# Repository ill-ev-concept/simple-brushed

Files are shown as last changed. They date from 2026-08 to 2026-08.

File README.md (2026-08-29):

# Ethan Brushed Simple

This is the simple version of the brushed motor controller for EV3, my current documentation can be found [here](https://docs.google.com/document/d/1gfZzmsv_RstbJ-Lk0RfqkkH_zSeoGgdf7qZ41NG-Wzg/edit?usp=sharing)

Additionally, the code can be found <a href = "https://gitlab.engr.illinois.edu/ev-concept/software2022-23/embedded/brushed-motors/brushed-motor-simple-26-27">here</a>

Currently works on the bench with minor modifications and problems:

 - Footprint for mosfet is reversed, so bodge wire was used to swap trace for gate pin
 - Buck converter possibly having some issues, previously worked in testing, but now doesnt function so it is being bypassed
 - Gate driver IC seems to pull down the STMs PWM signal to 2 volts peak, which is just enough for it to detect, but 3.3v is prefered

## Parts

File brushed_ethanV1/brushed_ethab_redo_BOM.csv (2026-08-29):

Reference | Qty | Value | DNP | Exclude from BOM | Exclude from Board | Footprint | Datasheet |  | ordered? | do I have in bring home box?
C1,C2,C4,C5,C7,C17,C18,C19 | 8 | .1uF |  |  |  | Capacitor_SMD:C_0805_2012Metric_Pad1.18x1.45mm_HandSolder |  |  | y | y but they are 0603
C3,C6 | 2 | 1uF |  |  |  | Capacitor_SMD:C_0805_2012Metric_Pad1.18x1.45mm_HandSolder |  |  | y | y
C8,C9 | 2 | C |  |  |  | Capacitor_THT:CP_Radial_D18.0mm_P7.50mm |  |  | y | y
C10,C11,C12 | 3 | 1.0uF |  |  |  | Capacitor_SMD:C_1206_3216Metric |  |  | y | y
C13 | 1 | 100nF |  |  |  | Capacitor_SMD:C_0603_1608Metric_Pad1.08x0.95mm_HandSolder |  |  | y | y
C14 | 1 | 100nF |  |  |  | Capacitor_SMD:C_0402_1005Metric_Pad0.74x0.62mm_HandSolder |  |  | y | y
C15,C16 | 2 | 10.0uF |  |  |  | Capacitor_SMD:C_1210_3225Metric |  |  | y | y
D1,D2 | 2 | LED |  |  |  | LED_SMD:LED_0805_2012Metric_Pad1.15x1.40mm_HandSolder |  |  | y | y
IC1 | 1 | TC1108-3.3VDBTR |  |  |  | SamacSys_Parts:SOT230P700X180-4N | http://ww1.microchip.com/downloads/en/DeviceDoc/21357C.pdf |  | y | y
J1 | 1 | RJ45 |  |  |  | Connector_RJ:RJ45_Amphenol_54602-x08_Horizontal |  |  | alr have | y
J2 | 1 | Conn_02x05_Odd_Even |  |  |  | Connector_PinSocket_2.54mm:PinSocket_2x05_P2.54mm_Vertical |  |  | alr have | y
J3 | 1 | Conn_01x03 |  |  |  | Connector_PinSocket_2.54mm:PinSocket_1x03_P2.54mm_Vertical |  |  | alr have | y
J4 | 1 | Conn_01x05 | DNP |  | Excluded from board | Connector_PinSocket_2.54mm:PinSocket_1x05_P2.54mm_Vertical
L1 | 1 | 22uH |  |  |  | Inductor_SMD:L_Bourns_SRR1208_12.7x12.7mm |  |  | y | y
M1 | 1 | Motor_DC |  |  | Excluded from board
MP1,MP2,MP3,MP4 | 4 | WP-BUFU |  |  |  | WP-BUFU:WP-BUFU_7461097 |  |  | y | y
Q2 | 1 | NTBLS4D0N15MC |  |  |  | SamacSys_Parts:NTBLS4D0N15MC | https://www.onsemi.com/pub/Collateral/NTBLS4D0N15MC-D.PDF |  | y | y
R1 | 1 | 120 |  |  |  | Resistor_SMD:R_0805_2012Metric_Pad1.20x1.40mm_HandSolder
R3 | 1 | 100k |  |  |  | Resistor_SMD:R_0402_1005Metric_Pad0.72x0.64mm_HandSolder |  |  | y | y
R4 | 1 | 7.15k |  |  |  | Resistor_SMD:R_0603_1608Metric_Pad0.98x0.95mm_HandSolder |  |  | y | y
R9 | 1 | 10 |  |  |  | Resistor_SMD:R_0805_2012Metric_Pad1.20x1.40mm_HandSolder |  | 10ohm | y | y
R10 | 1 | 10k |  |  |  | Resistor_SMD:R_0805_2012Metric_Pad1.20x1.40mm_HandSolder |  |  | y | y
R14,R15 | 2 | 300 |  |  |  | Resistor_SMD:R_0805_2012Metric_Pad1.20x1.40mm_HandSolder |  |  | alr have |  | ig not bringing these home
R16 | 1 | 100k |  |  |  | Resistor_SMD:R_0805_2012Metric_Pad1.20x1.40mm_HandSolder |  |  | y | y
R17 | 1 | 3k |  |  |  | Resistor_SMD:R_0805_2012Metric_Pad1.20x1.40mm_HandSolder |  |  | y | y
TP7 | 1 | TestPoint |  |  |  | TestPoint:TestPoint_Pad_D1.0mm
U1 | 1 | STM32F103C8Tx |  |  |  | Package_QFP:LQFP-48_7x7mm_P0.5mm | https://www.st.com/resource/en/datasheet/stm32f103c8.pdf |  | y | y
U2 | 1 | ISO1050DUB |  |  |  | Package_SO:SOP-8_6.62x9.15mm_P2.54mm | http://www.ti.com/lit/ds/symlink/iso1050.pdf |  | alr have | y
U3 | 1 | LMR51625YDDCR |  |  |  | BrushedDC2:BUCK_LMR51625YDDCR | https://www.ti.com/lit/gpn/lmr51625 |  | y | y
U4 | 1 | DGD0211CWT-7 |  |  |  | gatedriver:TSOT25-TH_DIO | DGD0211CWT-7 |  | y at home
U5 | 1 | STPS30H100DJF-TR |  |  |  | BrushedDC2:MOSFET_100DJF-TR_STM | https://www.st.com/resource/en/datasheet/stps30h100djf.pdf |  | y | y
VR1 | 1 | P120PK-Y25BR10K |  |  |  | SamacSys_Parts:P120PKY25BR10K | https://www.ttelectronics.com/TTElectronics/media/ProductFiles/Datasheet/P120.pdf |  | y | y

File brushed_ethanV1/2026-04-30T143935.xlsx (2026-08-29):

DigiKey - Shopping Cart
Index | Quantity | Part Number | Manufacturer Part Number | Description | Customer Reference | Available | Backorder | Unit Price | Extended Price USD
1 | 50 | 490-3261-1-ND | GRM155R71C104KA88D | CAP CER 0.1UF 16V X7R 0402 |  | 50 | 0 | 0.0156 | 0.78
2 | 25 | 445-4467-1-ND | C3216X7R2A105K160AA | CAP CER 1UF 100V X7R 1206 |  | 25 | 0 | 0.26 | 6.50
3 | 50 | 490-3285-1-ND | GRM188R72A104KA35D | CAP CER 0.1UF 100V X7R 0603 |  | 50 | 0 | 0.0584 | 2.92
4 | 25 | 587-MSASU32MSB5106KPNA01CT-ND | MSASU32MSB5106KPNA01 | CAP CER 10UF 50V X5R 1210 |  | 25 | 0 | 0.335 | 8.38
5 | 10 | 118-SRR1208-220MLCT-ND | SRR1208-220ML | FIXED IND 22UH 3.5A 43 MOHM SMD |  | 10 | 0 | 0.77 | 7.70
6 | 50 | 541-100KLCT-ND | CRCW0402100KFKED | RES 100K OHM 1% 1/16W 0402 |  | 50 | 0 | 0.0192 | 0.96
7 | 10 | 296-LMR51625XDDCRCT-ND | LMR51625XDDCR | SIMPLE SWITCHER SYNCHRONOUS BUCK |  | 10 | 0 | 1.545 | 15.45
8 | 10 | 497-15671-1-ND | STPS30H100DJF-TR | DIODE SCHOTTKY 100V 30A PWRFLAT |  | 10 | 0 | 1.181 | 11.81
9 | 25 | 311-100KCRCT-ND | RC0805FR-07100KL | RES 100K OHM 1% 1/8W 0805 |  | 25 | 0 | 0.0236 | 0.59
10 | 25 | A126368CT-ND | CRG0805F3K0 | RES SMD 3K OHM 1% 1/8W 0805 |  | 25 | 0 | 0.0276 | 0.69
11 | 50 | RMCF0603FT7K15CT-ND | RMCF0603FT7K15 | RES 7.15K OHM 1% 1/10W 0603 |  | 50 | 0 | 0.012 | 0.60
12 | 50 | 399-C0603C104K3RACTUCT-ND | C0603C104K3RACTU | CAP CER 0.1UF 25V X7R 0603 |  | 50 | 0 | 0.0358 | 1.79
13 | 10 | 1276-1066-1-ND | CL21B105KAFNNNE | CAP CER 1UF 25V X7R 0805 |  | 10 | 0 | 0.049 | 0.49
14 | 10 | 565-EKYB101ELL102MM40S-ND | EKYB101ELL102MM40S | CAP ALUM 1000UF 20% 100V RADIAL |  | 10 | 0 | 4.26 | 42.60
15 | 10 | 160-1179-1-ND | LTST-C170GKT | LED GREEN CLEAR SMD |  | 10 | 0 | 0.087 | 0.87
16 | 10 | TC1108-3.3VDBTRCT-ND | TC1108-3.3VDBTR | IC REG LIN 3.3V 300MA SOT-223-3 |  | 10 | 0 | 0.69 | 6.90
17 | 12 | 732-3217-ND | 7461097 | TERM REDCUBE M6 16PIN PCB |  | 12 | 0 | 3.013 | 36.16
18 | 10 | 488-NTBLS4D0N15MCCT-ND | NTBLS4D0N15MC | MOSFET N-CH 150V 19A/187A 8HPSOF |  | 10 | 0 | 5.164 | 51.64
19 | 10 | 541-10.0CCT-ND | CRCW080510R0FKEA | RES SMD 10 OHM 1% 1/4W 0805 |  | 10 | 0 | 0.044 | 0.44
20 | 50 | RMCF0805FT10K0CT-ND | RMCF0805FT10K0 | RES 10K OHM 1% 1/8W 0805 |  | 50 | 0 | 0.0156 | 0.78
21 | 4 | 497-17666-1-ND | STM32F103C8T6TR | IC MCU 32BIT 64KB FLASH 48LQFP |  | 4 | 0 | 6.15 | 24.60
22 | 4 | 987-1710-ND | P120PK-Y25BR10K | POT 10K OHM 1/20W PLASTIC LINEAR |  | 4 | 0 | 1.42 | 5.68

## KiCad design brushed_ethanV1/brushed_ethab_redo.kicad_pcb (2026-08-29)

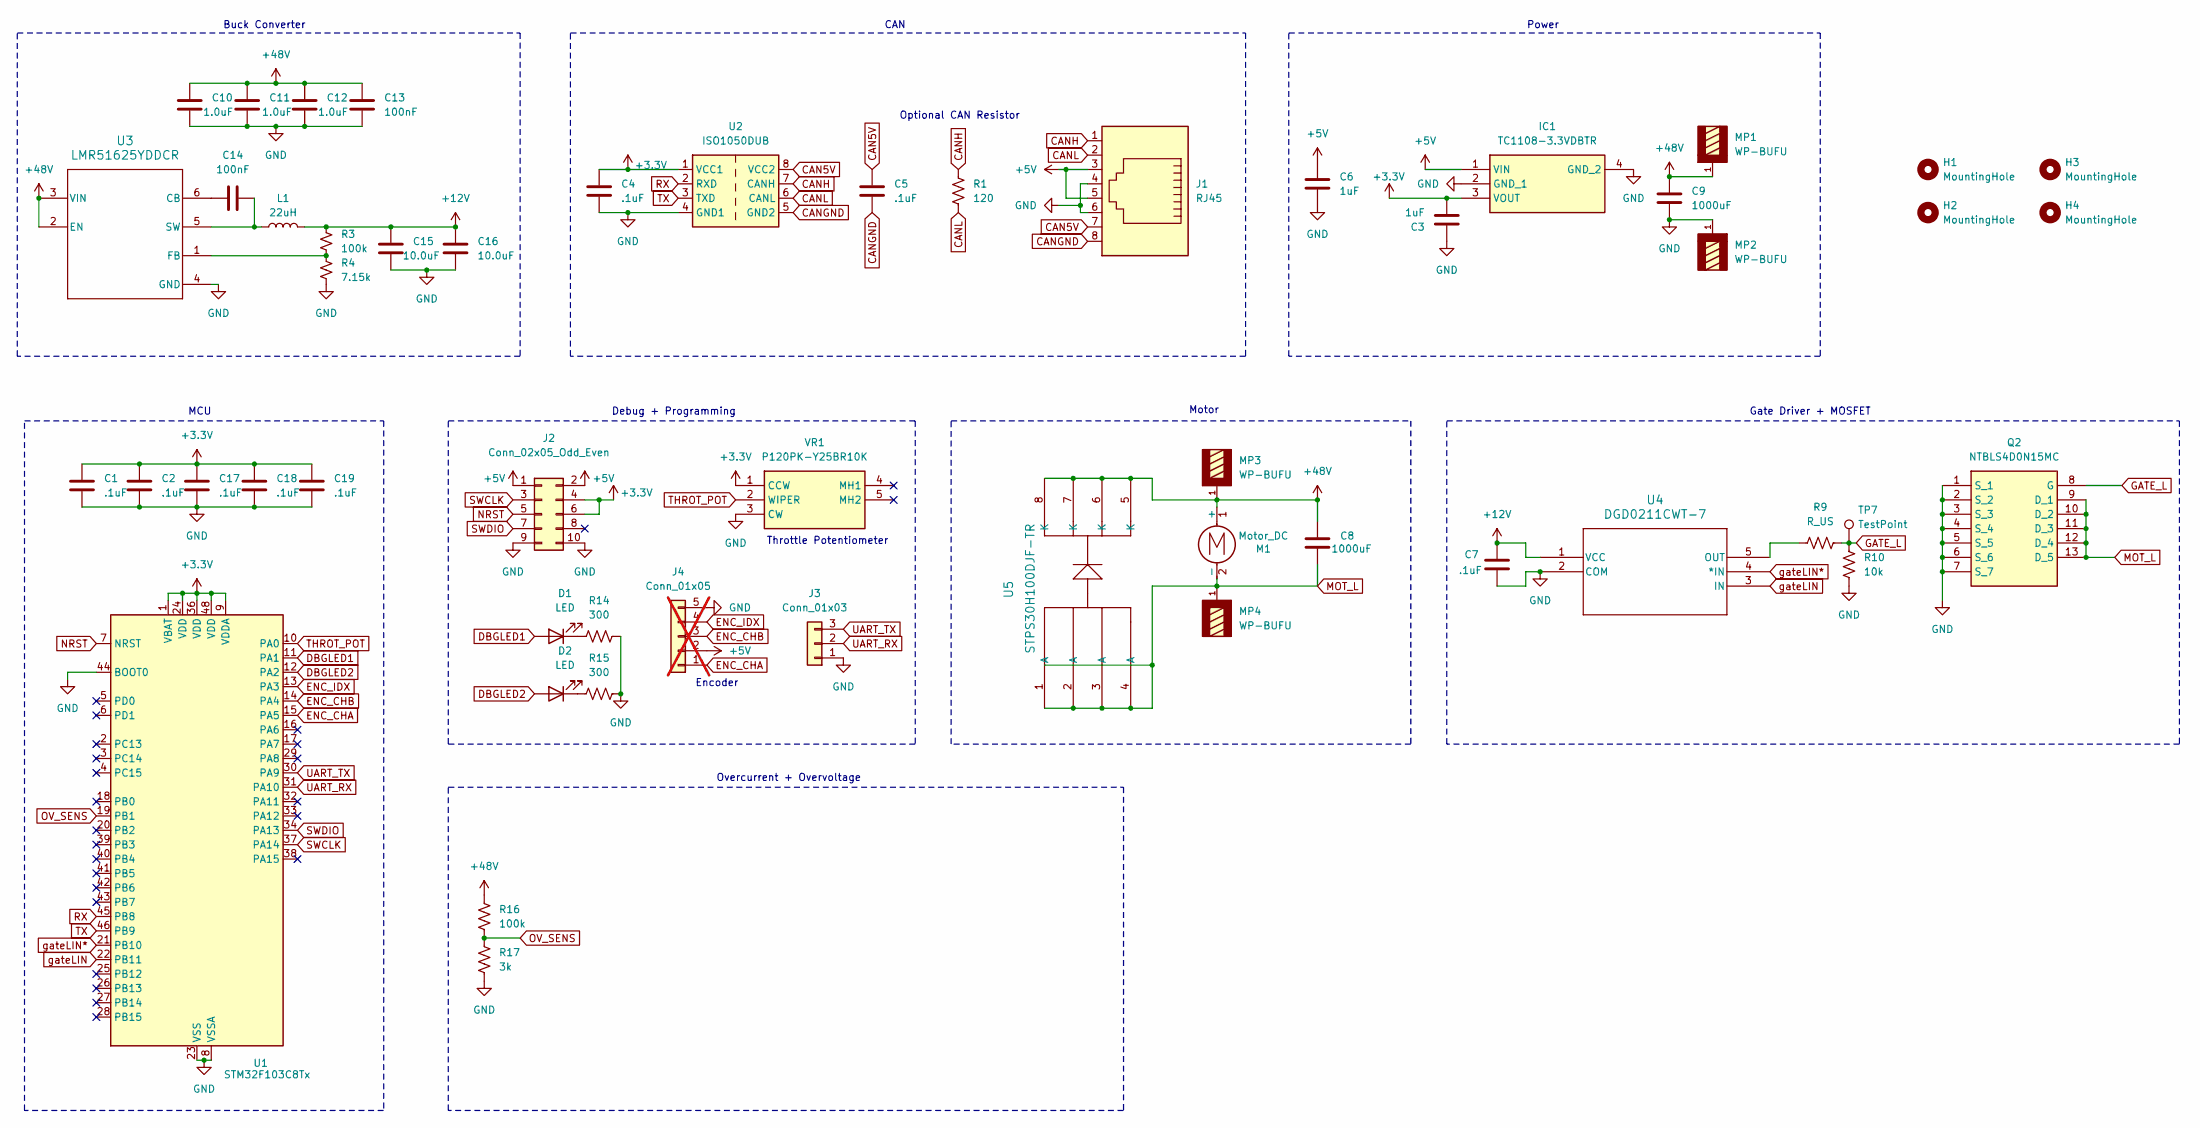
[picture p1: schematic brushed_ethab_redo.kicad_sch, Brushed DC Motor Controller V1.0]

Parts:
C1, C2, C4, C5, C7, C17, C18, C19: .1uF; C_0805_2012Metric_Pad1.18x1.45mm_HandSolder
C3, C6: 1uF; C_0805_2012Metric_Pad1.18x1.45mm_HandSolder
C8, C9: 1000uF; CP_Radial_D18.0mm_P7.50mm
C10, C11, C12: 1.0uF; C_1206_3216Metric
C13: 100nF; C_0603_1608Metric_Pad1.08x0.95mm_HandSolder
C14: 100nF; C_0402_1005Metric_Pad0.74x0.62mm_HandSolder
C15, C16: 10.0uF; C_1210_3225Metric
D1, D2: LED; LED_0805_2012Metric_Pad1.15x1.40mm_HandSolder
H1, H2, H3, H4: MountingHole; MountingHole_4.3mm_M4
IC1: TC1108-3.3VDBTR; SOT230P700X180-4N; Manufacturer_Part_Number TC1108-3.3VDBTR; Mouser Part Number 579-TC1108-3.3VDBTR
J1: RJ45; RJ45_Amphenol_54602-x08_Horizontal
J2: Conn_02x05_Odd_Even; PinSocket_2x05_P2.54mm_Vertical
J3: Conn_01x03; PinSocket_1x03_P2.54mm_Vertical
J4: Conn_01x05; PinSocket_1x05_P2.54mm_Vertical; not fitted
L1: 22uH; L_Bourns_SRR1208_12.7x12.7mm
M1: Motor_DC
MP1, MP2, MP3, MP4: WP-BUFU; WP-BUFU_7461097; DigiKey_Part_Number 732-3217-ND
Q2: NTBLS4D0N15MC; Manufacturer_Part_Number NTBLS4D0N15MC; Mouser Part Number 863-NTBLS4D0N15MC
R1: 120; R_0805_2012Metric_Pad1.20x1.40mm_HandSolder
R3: 100k; R_0402_1005Metric_Pad0.72x0.64mm_HandSolder
R4: 7.15k; R_0603_1608Metric_Pad0.98x0.95mm_HandSolder
R9: R_US; R_0805_2012Metric_Pad1.20x1.40mm_HandSolder
R10: 10k; R_0805_2012Metric_Pad1.20x1.40mm_HandSolder
R14, R15: 300; R_0805_2012Metric_Pad1.20x1.40mm_HandSolder
R16: 100k; R_0805_2012Metric_Pad1.20x1.40mm_HandSolder
R17: 3k; R_0805_2012Metric_Pad1.20x1.40mm_HandSolder
TP7: TestPoint; TestPoint_Pad_D1.0mm
U1: STM32F103C8Tx; LQFP-48_7x7mm_P0.5mm
U2: ISO1050DUB; SOP-8_6.62x9.15mm_P2.54mm
U3: LMR51625YDDCR; BUCK_LMR51625YDDCR
U4: DGD0211CWT-7; TSOT25-TH_DIO
U5: STPS30H100DJF-TR; MOSFET_100DJF-TR_STM
VR1: P120PK-Y25BR10K; P120PKY25BR10K; Manufacturer_Part_Number P120PK-Y25BR10K; Mouser Part Number 858-P120PKY25BR10K

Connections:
+3.3V: C1.1, C2.1, C3.2, C4.1, C17.1, C18.1, C19.1, IC1.3 (VOUT), J2.4, J2.6, U1.1 (VBAT), U1.9 (VDDA), U1.24 (VDD), U1.36 (VDD), U1.48 (VDD), U2.1 (VCC1), VR1.1 (CCW)
+5V: C6.1, IC1.1 (VIN), J1.3, J1.5, J2.1, J2.2, J4.2
+12V: C7.1, C15.1, C16.1, L1.2, R3.1, U4.1 (VCC)
+48V: C8.1, C9.1, C10.1, C11.1, C12.1, C13.1, M1.1 (+), MP1.1, MP1.2, MP1.3, MP1.4, MP1.5, MP1.6, MP1.7, MP1.8, MP1.9, MP1.10, MP1.11, MP1.12, MP1.13, MP1.14, MP1.15, MP1.16, MP3.1, MP3.2, MP3.3, MP3.4, MP3.5, MP3.6, MP3.7, MP3.8, MP3.9, MP3.10, MP3.11, MP3.12, MP3.13, MP3.14, MP3.15, MP3.16, R16.2, U3.2 (EN), U3.3 (VIN), U5.5 (K), U5.6 (K), U5.7 (K), U5.8 (K)
CAN5V: C5.1, J1.7, U2.8 (VCC2)
CANGND: C5.2, J1.8, U2.5 (GND2)
CANH: J1.1, R1.1, U2.7 (CANH)
CANL: J1.2, R1.2, U2.6 (CANL)
DBGLED1: D1.2 (A), U1.11 (PA1)
DBGLED2: D2.2 (A), U1.12 (PA2)
ENC_CHA: J4.1, U1.15 (PA5)
ENC_CHB: J4.3, U1.14 (PA4)
ENC_IDX: J4.4, U1.13 (PA3)
GATE_L: Q2.8 (G), R9.2, R10.2, TP7.1 (1_1)
GND: C1.2, C2.2, C3.1, C4.2, C6.2, C7.2, C9.2, C10.2, C11.2, C12.2, C13.2, C15.2, C16.2, C17.2, C18.2, C19.2, IC1.2 (GND_1), IC1.4 (GND_2), J1.4, J1.6, J2.9, J2.10, J3.1, J4.5, MP2.1, MP2.2, MP2.3, MP2.4, MP2.5, MP2.6, MP2.7, MP2.8, MP2.9, MP2.10, MP2.11, MP2.12, MP2.13, MP2.14, MP2.15, MP2.16, Q2.1 (S_1), Q2.2 (S_2), Q2.3 (S_3), Q2.4 (S_4), Q2.5 (S_5), Q2.6 (S_6), Q2.7 (S_7), R4.2, R10.1, R14.2, R15.2, R17.1, U1.8 (VSSA), U1.23 (VSS), U1.35 (VSS), U1.44 (BOOT0), U1.47 (VSS), U2.4 (GND1), U3.4 (GND), U4.2 (COM), VR1.3 (CW)
MOT_L: C8.2, M1.2 (-), MP4.1, MP4.2, MP4.3, MP4.4, MP4.5, MP4.6, MP4.7, MP4.8, MP4.9, MP4.10, MP4.11, MP4.12, MP4.13, MP4.14, MP4.15, MP4.16, Q2.9 (D_1), Q2.10 (D_2), Q2.11 (D_3), Q2.12 (D_4), Q2.13 (D_5), U5.1 (A), U5.2 (A), U5.3 (A), U5.4 (A)
NRST: J2.5, U1.7 (NRST)
unnamed: D1.1 (K), R14.1
unnamed: D2.1 (K), R15.1
unnamed: C14.1, U3.6 (CB)
unnamed: R3.2, R4.1, U3.1 (FB)
unnamed: C14.2, L1.1, U3.5 (SW)
unnamed: R9.1, U4.5 (OUT)
OV_SENS: R16.1, R17.2, U1.19 (PB1)
RX: U1.45 (PB8), U2.2 (RXD)
SWCLK: J2.3, U1.37 (PA14)
SWDIO: J2.7, U1.34 (PA13)
THROT_POT: U1.10 (PA0), VR1.2 (WIPER)
TX: U1.46 (PB9), U2.3 (TXD)
UART_RX: J3.2, U1.31 (PA10)
UART_TX: J3.3, U1.30 (PA9)
gateLIN: U1.22 (PB11), U4.3 (IN)
gateLIN*: U1.21 (PB10), U4.4 (*IN)

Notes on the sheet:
Buck Converter
Power
Encoder
Optional CAN Resistor
Throttle Potentiometer
Motor
MCU
CAN
Gate Driver + MOSFET
Overcurrent + Overvoltage
Debug + Programming

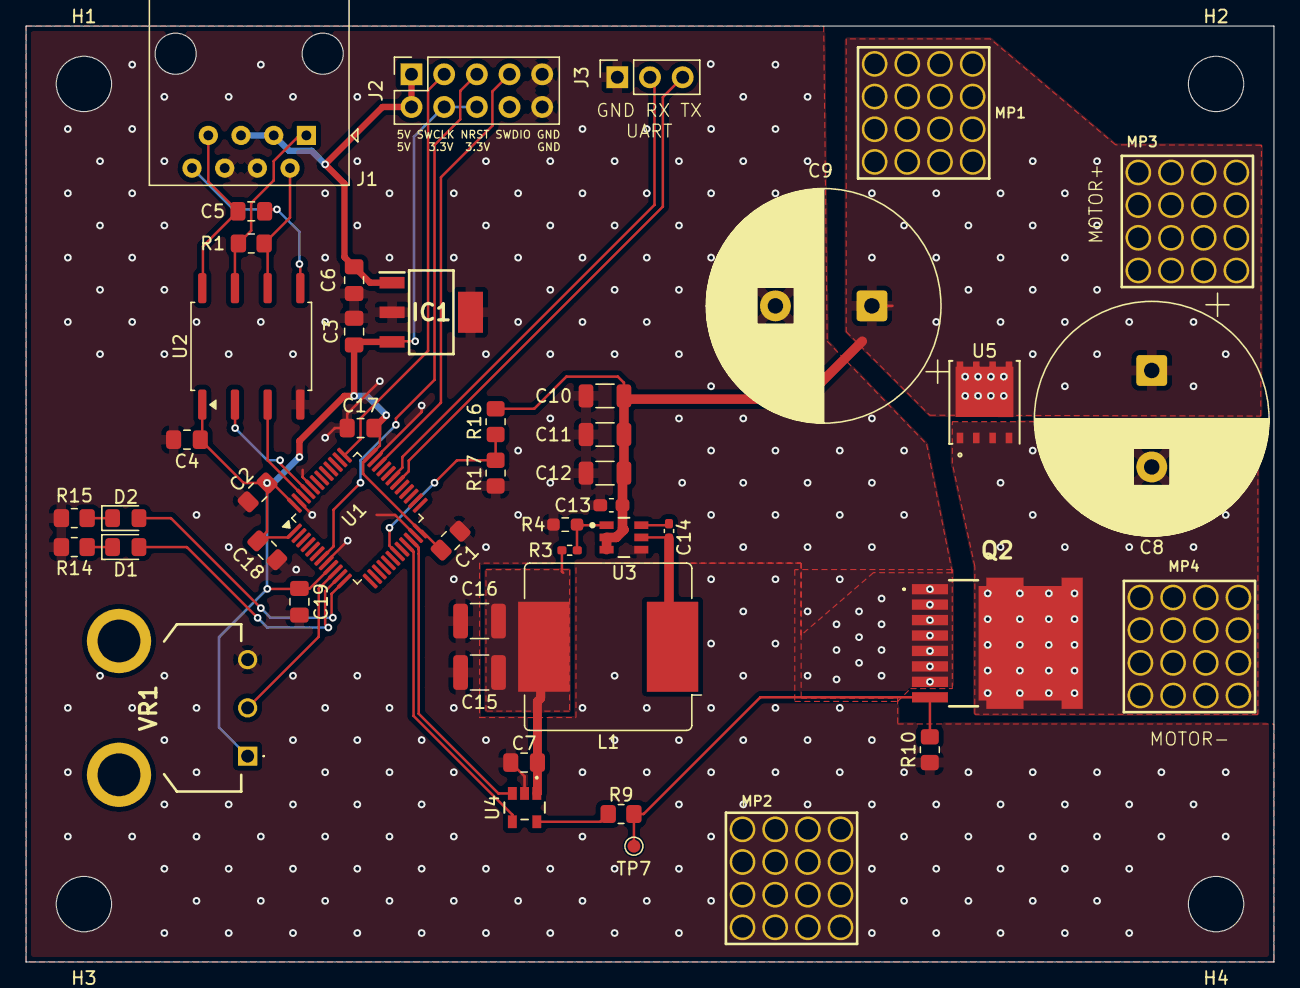
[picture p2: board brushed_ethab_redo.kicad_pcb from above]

Board: 2 copper layers, 97.0 x 72.8 mm, 51 parts (0 on the bottom side), 30 nets.
